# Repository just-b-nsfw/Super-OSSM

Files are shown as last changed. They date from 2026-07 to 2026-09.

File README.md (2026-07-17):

# Super-OSSM
Introducing the Super OSSM
A clean sheet, modular design, for a choose your OSSM build adventure.

Building on community improvements to the R+D design, the Super OSSM is compatible with 4 motor types, 2 PCBs, 3 rail & belt sizes, with 2 drive types to choose from, plus add-on modules.

My approach is to make it compact and compatible, only increasing the diameter by 15mm from the standard PitClamp ring, whilst being able to offer a wide range of compatibility for different-sized components. 

Large focus on - reducing the number of parts required, with the main unit being only 4 3D printed parts - simplifying the BOM, with standardised bolt sizes & lengths and using standard OSSM parts - ease of 3D printing, by minimising the need for support material - and improved assembly & serviceability,  with a twist-lock to access the motor and PCB. 
The final goal has been to improve the overall aesthetics so that the Super OSSM looks like a finished product rather than a DIY project.

Unfortunately, two design compromises were made - first, support and compatibility for the legacy iHSV motor was not possible, due to the backpack electronics that it has, making packaging inside the Super OSSM impossible - second, the use of 688 (8x16x8mm) bearings, rather than standard OSSM bearings, to aid ease of assembly.

Design features include a larger version of @Armpit’s PitClamp design with 120 position / 3° increments, and a fixed or folding clamp option for easy under-bed storage.

Support for @BuildingRandomStuff’s ALT PCB and the R+D PCB, with a translucent logo for the status LED.

An alternative drive option to use @SaladDressing’s Capstan drive system.

Support for -  
Motors	:	42AIM, 57AIM, 60AIM series & 60AIM40F  
PCB	:	R+D & ALT  
Rails	:	MGN12, MGN15 & HGR20  
Drive Mechanism	:	Belt or Capstan  
Belts	:	2MGT, 3MGT & HTD-3M  
Add-ons	:	Stroker Module 	(hopefully more in future)

Special thanks to @Frayd for their input and putting up with me being "extra" on calls to discuss the project.

I hope to have designed an OSSM for one and an OSSM for all.

b

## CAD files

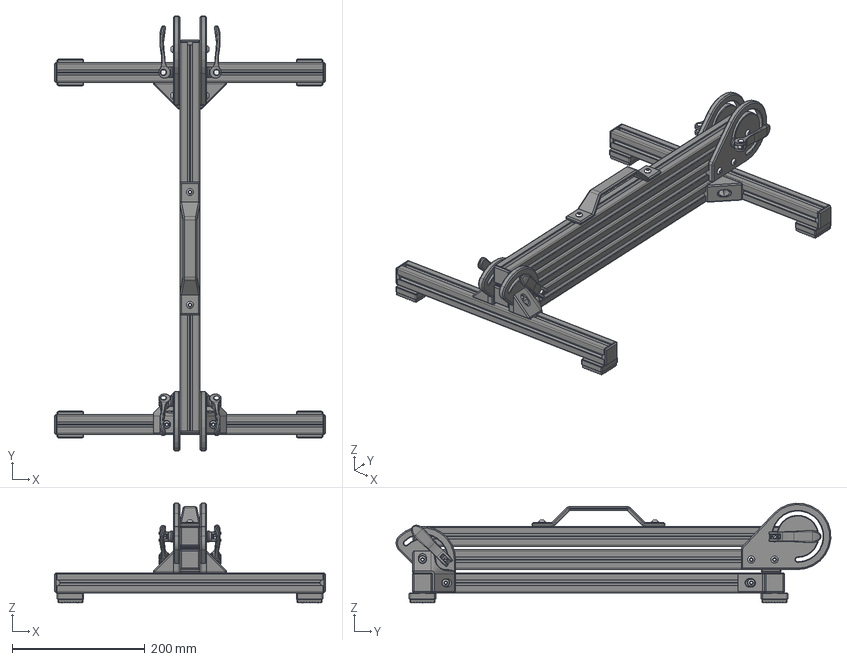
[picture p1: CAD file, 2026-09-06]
7. Z Stand/3030/Z Stand (3030) - Assembly.step
408.0 x 654.5 x 149.9 mm
5720K31_Clamping Handle with Threaded Stud x 4
91239A326_Button Head Hex Drive Screw x 4
91239A813_Button Head Hex Drive Screw x 10
91239A318_Button Head Hex Drive Screw x 10
91239A316_Button Head Hex Drive Screw x 2

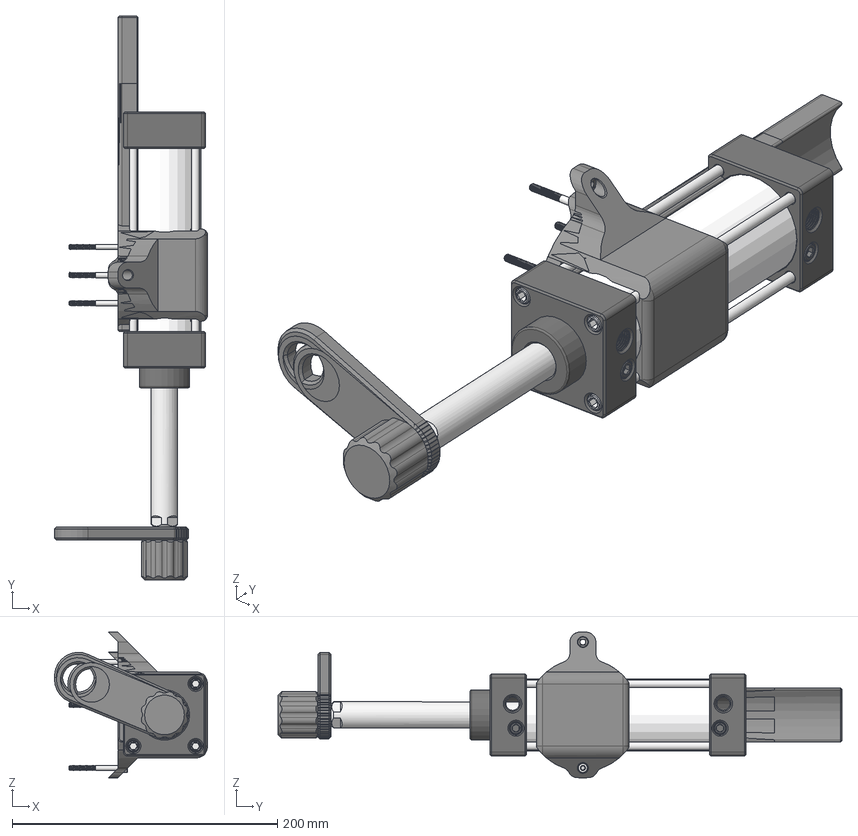
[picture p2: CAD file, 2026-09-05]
8. Add-on Modules/SC50 Stroker Module/SC50 Stroker Module - Assembly.step
115.5 x 425.5 x 110.0 mm
SC50X25_c
SC-50x25(0)_r
91292A132_18-8 Stainless Steel Socket Head Screw x 4

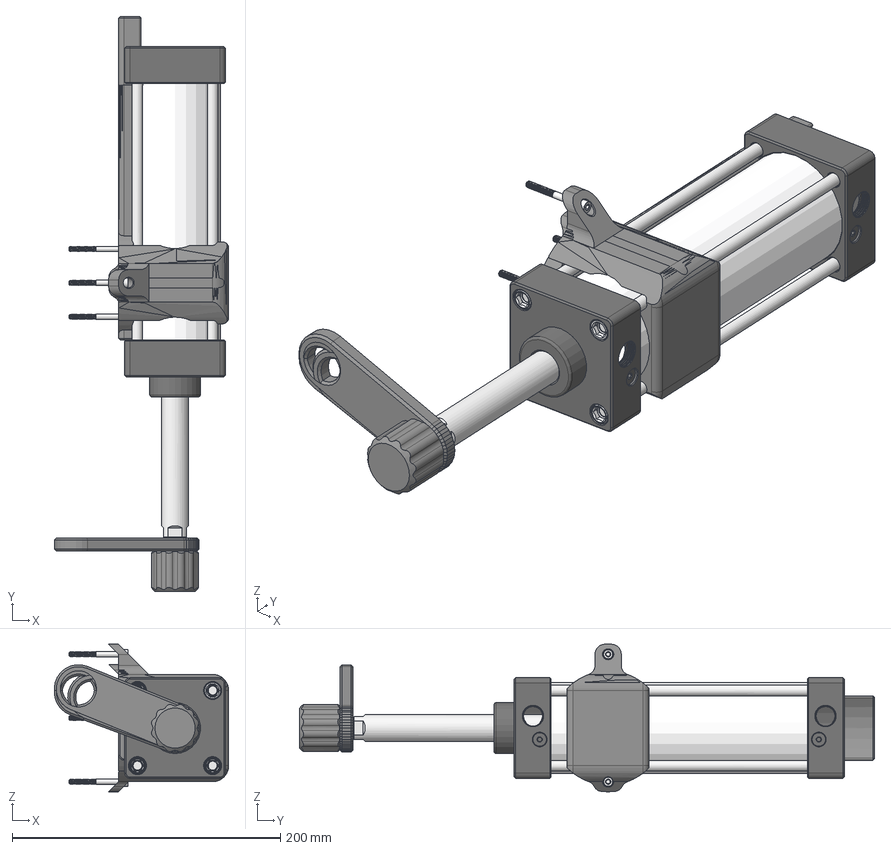
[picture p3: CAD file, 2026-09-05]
8. Add-on Modules/SC63 Stroker Module/SC63 Stroker Module - Assembly.step
130.0 x 428.5 x 110.0 mm
SC2563
SC63X25-S_00_rod
91292A132_18-8 Stainless Steel Socket Head Screw x 4

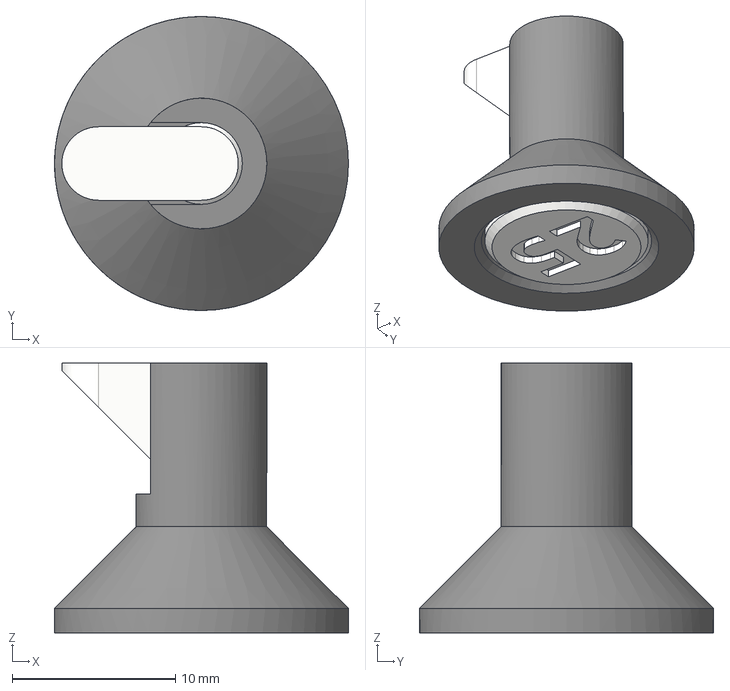
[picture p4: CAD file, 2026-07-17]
0. Test & Calibration/Step/Button (0.25).step
18.0 x 18.0 x 16.5 mm

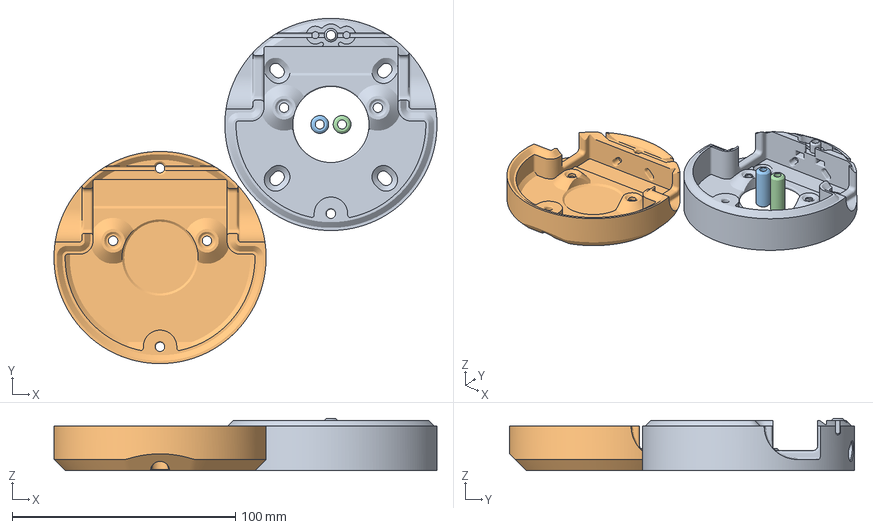
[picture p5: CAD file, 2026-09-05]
1. Super OSSM/Head (Std)/Head (Std).3mf
171.5 x 154.6 x 23.4 mm
Base (Std).stl
Cover (Std).stl
Bearing Carrier.stl x 2

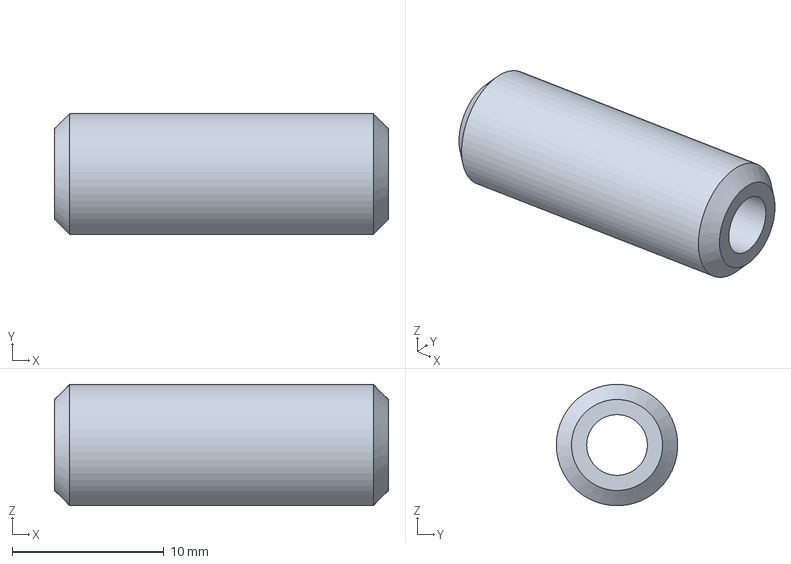
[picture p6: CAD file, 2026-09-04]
1. Super OSSM/Head (Std)/Step/Bearing Carrier.step
22.0 x 7.99 x 8.00 mm

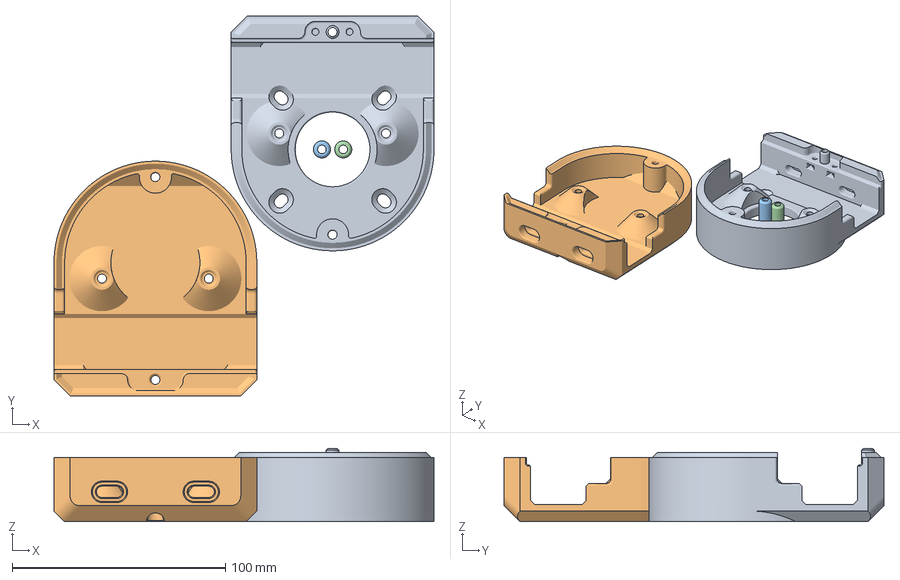
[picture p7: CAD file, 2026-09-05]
1. Super OSSM/Head (XL)/Head (XL).3mf
178.0 x 178.0 x 34.4 mm
Base (XL).stl
Cover (XL).stl
Bearing Carrier.stl x 2

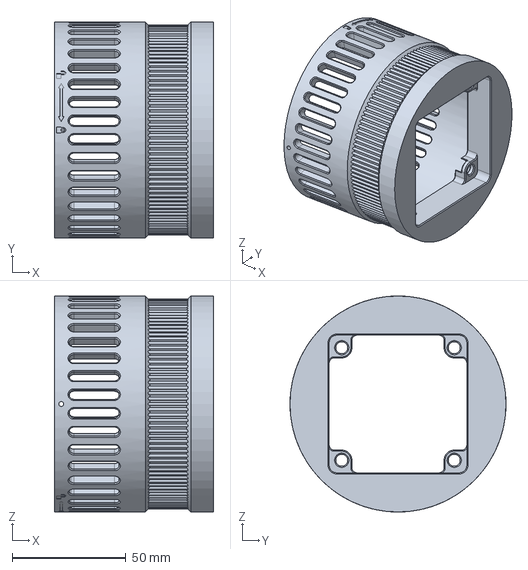
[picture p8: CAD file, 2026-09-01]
1. Super OSSM/Main Body/Step/Motor Ring (60AIM40F).step
70.0 x 95.0 x 95.0 mm

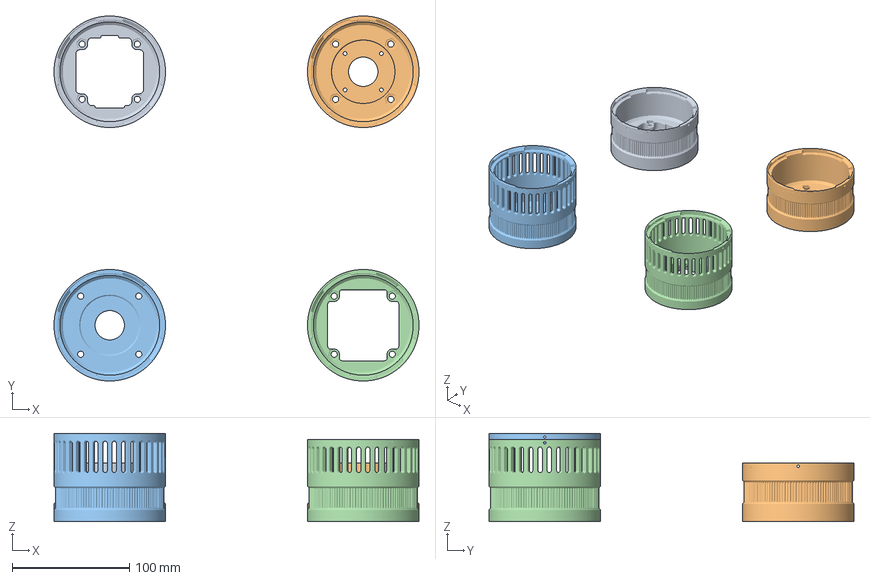
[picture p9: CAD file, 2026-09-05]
1. Super OSSM/Main Body/Super OSSM - Motor Ring.3mf
311.0 x 311.0 x 75.0 mm
Motor Ring (57AIM).stl
Motor Ring (42AIM).stl
Motor Ring (60AIM).stl
Motor Ring (60AIM40F).stl

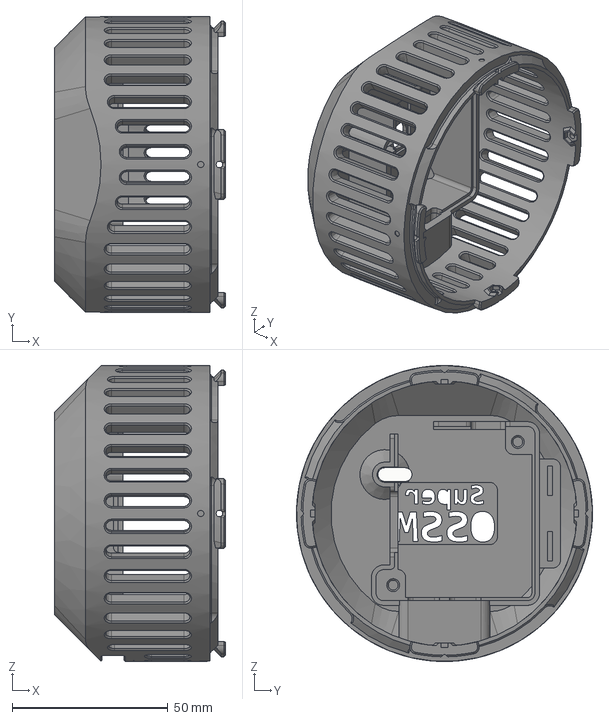
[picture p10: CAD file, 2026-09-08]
1. Super OSSM/PCB Housing/Step/ALT Cover (Dev).step
55.0 x 95.0 x 95.0 mm

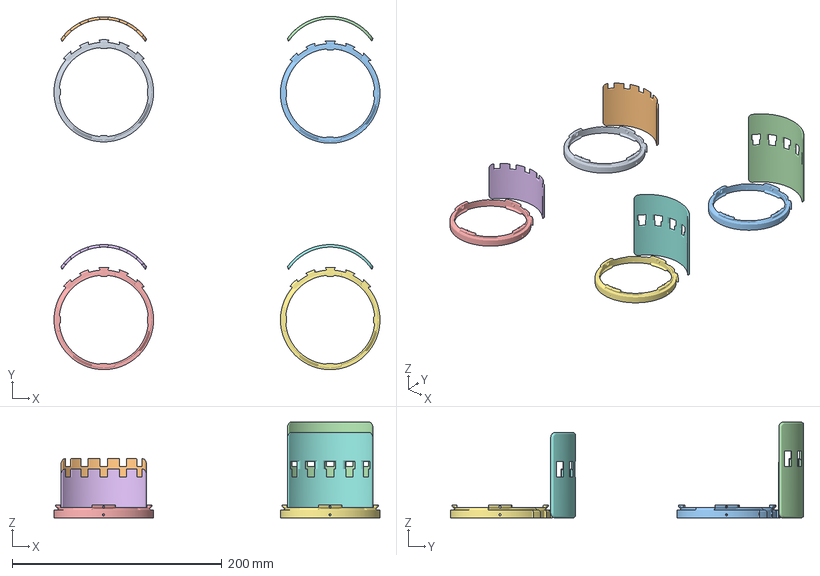
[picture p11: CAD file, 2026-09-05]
1. Super OSSM/Splash Guard/Splash Guard.3mf
311.0 x 337.0 x 91.5 mm
Ring.stl x 4
Guard (R+D).stl
Guard (R+D) (XL).stl
Guard (ALT).stl
Guard (ALT) (XL).stl

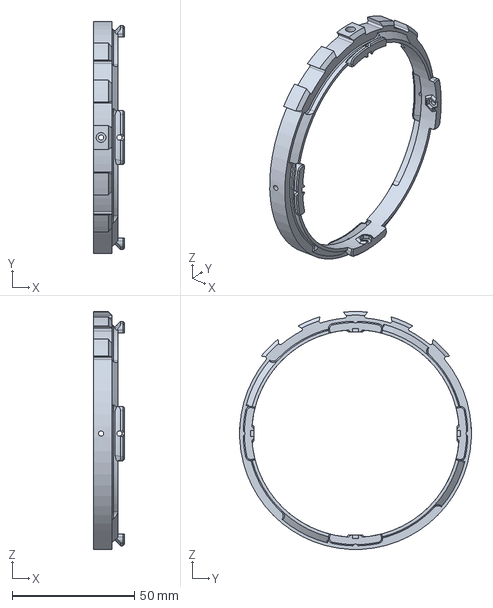
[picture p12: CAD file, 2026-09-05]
1. Super OSSM/Splash Guard/Step/Ring.step
12.5 x 95.0 x 97.5 mm

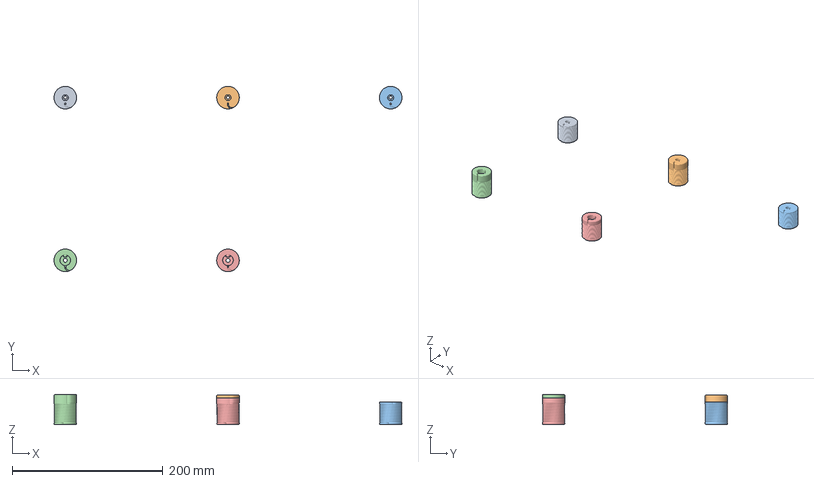
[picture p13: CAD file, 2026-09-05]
2. Motors & Pulleys/Capstan Drum/Capstan Drum.3mf
462.0 x 246.0 x 40.0 mm
Drum - 57AIM (Std).stl
Drum - 57AIM (XL).stl
Drum - 42AIM (std).stl
Drum - 60AIM (XL).stl
Drum - 60AIM40F (XL).stl

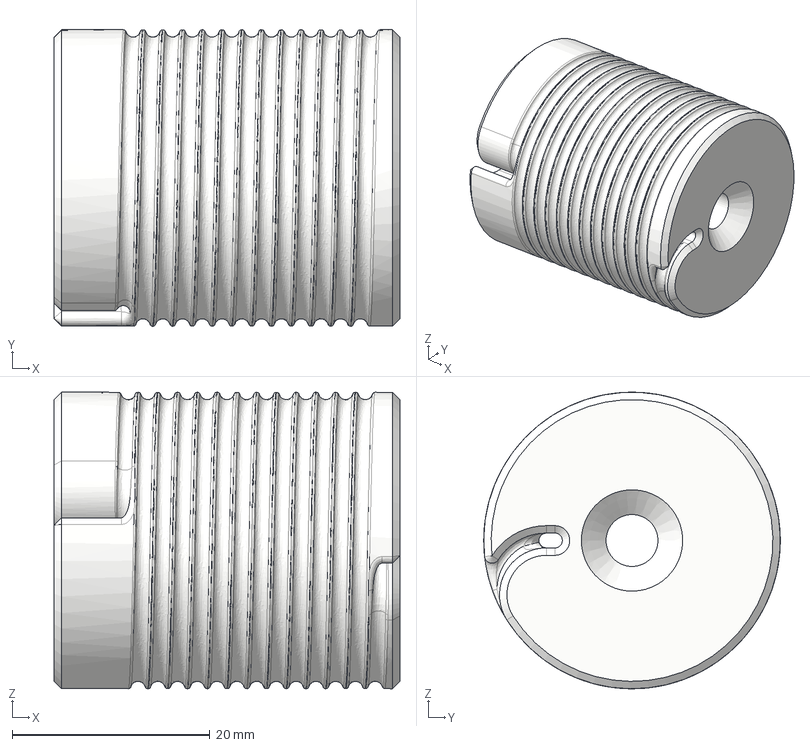
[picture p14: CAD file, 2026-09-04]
2. Motors & Pulleys/Capstan Drum/Step/Drum - 60AIM40F (XL).step
35.0 x 30.0 x 30.0 mm

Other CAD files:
1. Super OSSM/Head (XL)/Step/Bearing Carrier.step
2. Motors & Pulleys/Shaft Extender.3mf
3. Rail Ends/12mm Rail/12mm Rail.3mf
3. Rail Ends/12mm Rail/Step/Tensioner Adapter (12mm).step
0. Test & Calibration/Step/Button (0.20).step
0. Test & Calibration/Step/Button (0.30).step
0. Test & Calibration/Step/Button (0.35).step
0. Test & Calibration/Step/Super OSSM Calibration.step
0. Test & Calibration/Step/Tensioner Cover.step
0. Test & Calibration/Step/Thread.step
0. Test & Calibration/Step/Twist-lock A.step
0. Test & Calibration/Step/Twist-lock B.step
0. Test & Calibration/Stl/Button (0.20).stl
0. Test & Calibration/Stl/Button (0.25).stl
0. Test & Calibration/Stl/Button (0.30).stl
0. Test & Calibration/Stl/Button (0.35).stl
0. Test & Calibration/Stl/Super OSSM Calibration.stl
0. Test & Calibration/Stl/Thread.stl
0. Test & Calibration/Stl/Twist-lock A.stl
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

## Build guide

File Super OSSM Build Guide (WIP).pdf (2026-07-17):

## Build &

### Assembly Guide

Super

## OSSM

Introducing the Super OSSM A clean sheet, modular design, for a choose your OSSM build adventure.
Building on community improvements to the R+D design, the Super OSSM is compatible with 4 motor types, 2 PCBs, 3 rail & belt sizes, with 2 drive types to choose from, plus add-on modules.
My approach is to make it compact and compatible, only increasing the diameter by 15mm from the standard PitClamp ring, whilst
being able to offer a wide range of
compatibility for different sized components.

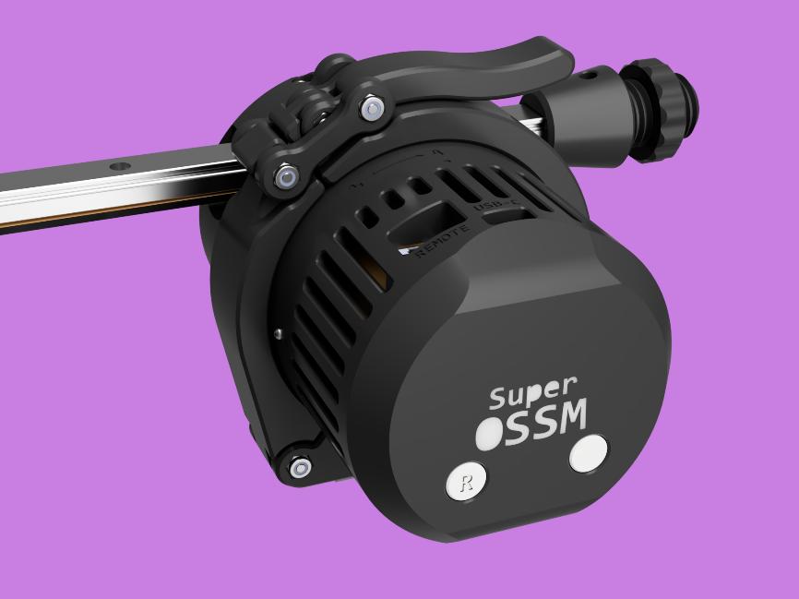
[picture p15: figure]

Large focus on - reducing the number of parts required, with the main unit being only 4 3D printed parts -simplifying the BOM, with standardised bolt sizes & lengths and using standard OSSM parts - ease of 3D printing, by minimising the need for support material - and improved assembly & serviceability, with a twist-lock to access the motor and PCB.
The final goal has been to improve the overall aesthetics so that the Super OSSM looks like a finished product rather than a DIY project.
Unfortunately, two design compromises were made - first, support and compatibility for the legacy iHSV motor was not possible, due to the backpack electronics that it has, making packaging inside the Super OSSM impossible - second, the use of 688 (8x16x8mm) bearings, rather than standard OSSM bearings, to aid ease of assembly.
Design features include a larger version of @Armpit’s PitClamp design with 120 position / 3° increments, and a fixed or folding clamp option for easy under-bed storage.
Support for @BuildingRandomStuff’s ALT PCB and the R+D PCB, with a translucent logo for the status LED. An alternative drive option to use @SaladDressing’s Capstan drive system.
Support for -
Motors | : 42AIM, 57AIM, 60AIM series & 60AIM40F
PCB | : R+D & ALT
Rails | : MGN12, MGN15 & HGR20
Drive Mechanism : Belt or Capstan
Belts | : 2MGT, 3MGT & HTD-3M
Add-ons | : Stroker Module | (hopefully more in future)
Special thanks to @Frayd for their input and putting up with me being "extra" on calls to discuss the project. I hope to have designed an OSSM for one and an OSSM for all.

b

This build and assembly guide is written to give an overview of the 3D printing, build and assembly process for the Super OSSM, from printing to play.
Print order and assembly steps are set out in a logical order for you to start building your Super OSSM as soon as the first parts are 3D printed. Due to the modularity of the design, not all configurations may be shown, and common sense may be needed. If bolt lengths are not specified in a step, please refer to the BOM. First time builders it is recommended that you join the Kinky Makers Discord server as it is a wealth of knowledge, a great place to chat with like-minded Kinky Makers, share and show-off projects, get help and technical or troubleshooting advice, and contribute to the Open-Source Sex Machine project.
Step 1 : Choose your OSSM build adventure
- Determine if you want a Standard, Lite or XL build - depending on the size of toys and attachments you plan to use, including any add-ons.
- Select an appropriate motor and rail size.
- Decide on drive system - belt or capstan.
- Choose your PCB.

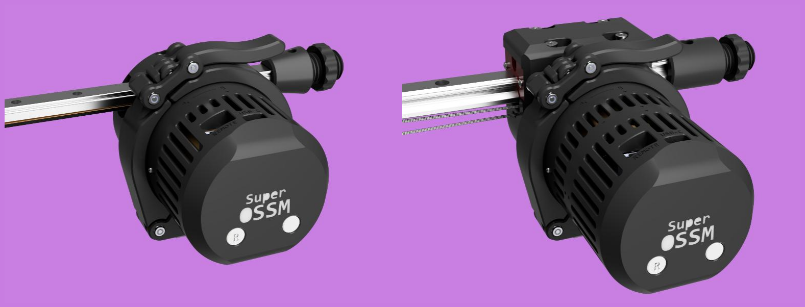
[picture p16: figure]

Recommended Configurations
Build | Head | PCB | Motor | Mechanism Drive | Belt | Rail Type | Rail Length | Attachment Weight | Add-ons*
Lite | Std | R+D ALT | 42AIM 57AIM | Belt | 2MGT x 12 mm | MGN12 | ≤ 400 mm | ≤ 2 kg | Stroker Module
Std | Std | R+D ALT | 57AIM | Belt Capstan | 2MGT x 15 mm 3MGT x 15 mm 1.5~2 mm Dyneema | MGN15 | 500 mm 350 ~ | 2 ~ 3kg | Stroker Module
XL | XL | R+D ALT | 60AIM 60AIM40F | Belt Capstan | 1.5~2 mm Dyneema HTD-3M x 15 mm | HG20R | ≥ 500 mm | ≥ 3 kg | Stroker Module

* High-torque motors are required to operate the Super OSSM as a stroker and poker simultaneously.
Parts are modular so you can customise your Super OSSM, depending on preferences and parts availability.

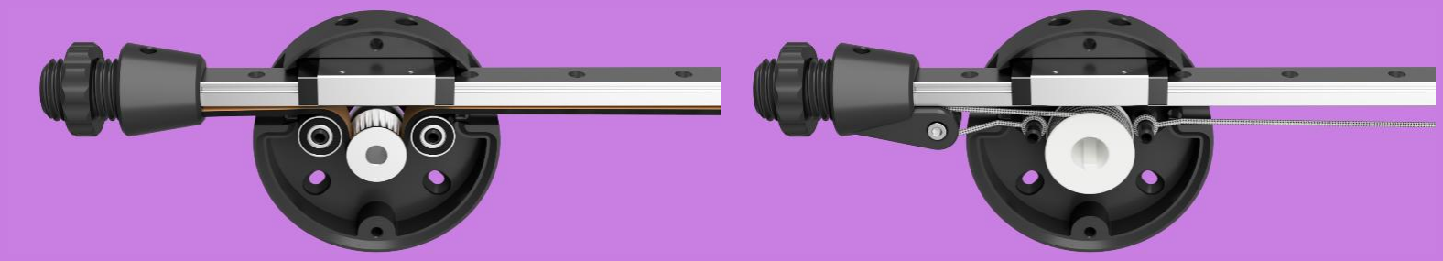
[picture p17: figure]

Compatible Motors
Motor | Protocol** | Dimensions | Shaft Size | Rated Speed | Max Speed | Torque | Voltage | Current | Power
42AIM10 | RS485 | ⌀ 53 x 42 mm | ⌀ 8 x 23 mm | 1000 RPM | 1500 RPM | 0.33 NM | 24 ~ 36 V | 1.5 A | 33 W
42AIM15 | RS485 | ⌀ 53 x 55 mm | ⌀ 8 x 27 mm | 1000 RPM | 1500 RPM | 0.48 NM | 24 ~ 36 V | 2.2 A | 50 W
42AIM30* | RS485 | ⌀ 53 x 70 mm | ⌀ 8 x 27 mm | 1000 RPM | 1500 RPM | 0.96 NM | 24 ~ 36 V | 4.4 A | 100 W
57AIM15 | RS485 | 57 x 57 x 57 mm | ⌀ 8 x 26 mm | 1000 RPM | 1500 RPM | 0.48 NM | 24 ~ 36 V | 2.2 A | 50 W
57AIM30* | RS485 | 57 x 57 x 72 mm | ⌀ 8 x 26 mm | 1000 RPM | 1500 RPM | 0.96 NM | 24 ~ 36 V | 4.4 A | 100 W
60AIM25* | RS485 | ⌀ 80 x 76 mm | ⌀ 14 x 30 mm | 1000 RPM | 1500 RPM | 2 NM | 36 V | 7.0 A | 200 W
60AIM40* | RS485 | ⌀ 80 x 90 mm | ⌀ 14 x 30 mm | 1000 RPM | 1500 RPM | 3 NM | 36 V | 10.0 A | 350 W
60AIM40F* | RS485 | 60 x 60 x 92 mm | ⌀ 14 x 30 mm | 1000 RPM | 1500 RPM | 2 NM | 36 V | 7.0 A | 200 W
* Recommended motors ** Recognisable by the GREEN terminal on the motor Note : 57AIM30 motor is often referred to as the “Gold” motor, and is the standard OSSM motor available from R+D. Comparison video of some of the available motors

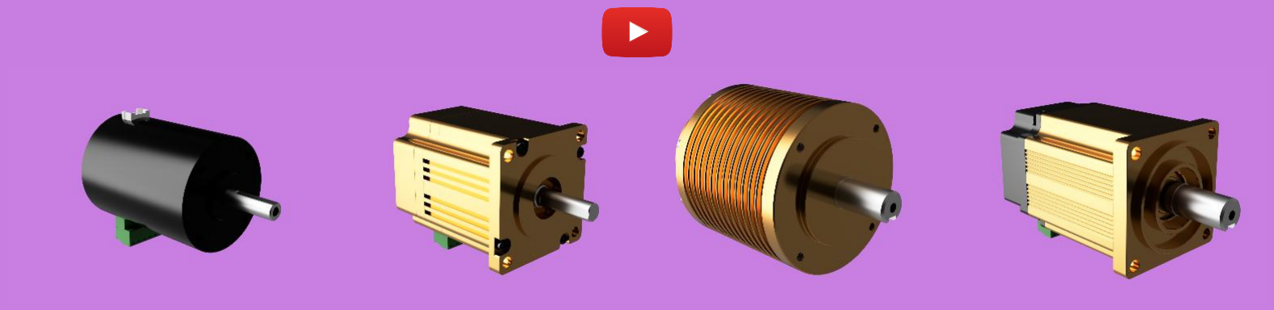
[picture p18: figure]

Compatible Rails
Rail | Dimensions | Hole Size | Spacing Hole | Length | Carriage | Dimensions | Bolt Size | Bolt Spacing
MGN12 | 12 x 8 mm | M3 | 25 mm | ≤ 400 mm | MGN12H | 45 x 27 x 13 mm | M3 x 3.5 mm | 20 x 20 mm
MGN15 | 15 x 10 mm | M3 | 40 mm | 350 ~ 500 mm | MGN15H | 59 x 32 x 16 mm | M3 x 4 mm | 25 x 25 mm
HGR20 | 20 x 17.5 mm | M5 | 60 mm | ≥ 500 mm | HGH20HA QHH20A | 92 x 44 x 30 mm | M5 x 6 mm | 50 x 32 mm

Max Stroke Length = Rail Length – Head Width – Rail Ends
Head Width : Std 70 mm | XL 95 mm
Rail Ends : MGN12 65 mm | MGN15 80 mm | HGR20 80 mm
Rail Length [400 mm] – Std Head Width [70 mm] – MGN15 Rail Ends [80 mm] = Max Stroke Length [250 mm]
Step 20 : Order parts
- See the BOM for the full parts list.
- You can order a kit from R+D - including 57AIM “Gold” motor, PCB + Remote, Rail & Hardware
- or source parts yourself | (required for alternative builds)

Step 3 : Calibrate your 3D printer Recommended print settings :
- Material | – PETG, ABS, PLA+ | DO NOT USE CF FILAMENTS!
- Nozzle | - 0.4 mm
- Perimeters - 4 | 8 for threaded rail ends | (minimum for strength vs print time)
- Infill | - 25% | 50% for threaded rail ends
- Layer height - 0.16 mm
- Wall order - Inside / Outside | (improves quality of threads and overhangs)
- Support | - NO for test prints | 40° for parts | (recommend paint-on supports)
Note : It is recommended that all parts for the project are printed on the same 3D printer to ensure that all parts fit together and account for any minor variations. Print the included calibration files to confirm dimensional accuracy :
- Check that the test print is the correct size 50 x 35 x 5 mm (± 0.1 mm) and the fasteners fit through the holes.
| | – Top holes are actual size - M3 = 3.0 mm
– Middle holes are 5% larger - M3 = 3.15 mm – Counterbores are 0.5 mm larger than the fastener head – M3 head 5.5 mm = 6.0 mm – Hexes are actual size for press fit so the captive nuts are securely – M3 hex 5.5 mm = 5.5 mm
- Print-in-place button has a 0.3 mm offsetfor a snug fit, which does notrattle, whilst being easy to print and operate smoothly. The button should require a firm push to free it after printing.
- Twist-lock should be a tight fit, to account for wear from use, and will operate more freely with a satisfying click after opening and closing a couple of times.

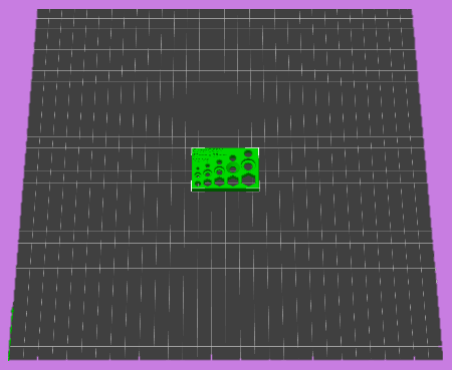
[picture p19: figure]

Troubleshooting :

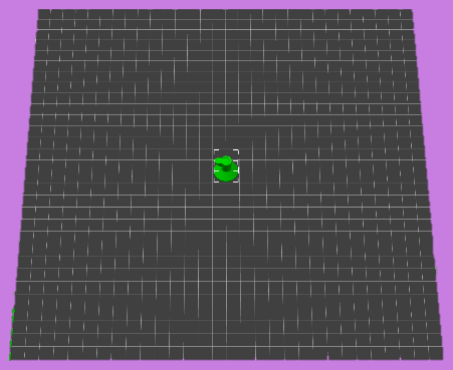
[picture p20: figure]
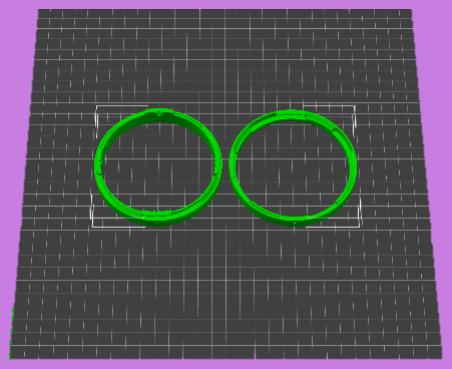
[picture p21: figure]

If you have difficulty with the test prints, check the following settings BEFORE you print the Super OSSM.
- Extrusion multiplier – complete a Flow Ratio test to ensure that your printer is not over-extruding as over-extrusion can cause the print-in-place button to print solid, undersized
holes and parts that do not fit together. | (OrcaSlicer has built-in calibration tools)
- XY contour compensation – if parts are over or undersized and do not fit together.
- XY hole compensation – if holes are undersized whilst the rest of the part is the correct
dimension [0.15 mm recommended] | (if your preferred slicer has the setting)
- Dynamic speeds and cooling for bridging and overhangs - there are parts that need clean 45° surfaces and bridged overhangs for embossed text.
- General print settings, including supports for best print quality and easy removal – whilst the Super OSSM has been designed to minimise support material where possible, there are areas where it is unavoidable such as spaces for captive nuts, PCB ports etc.

Step 4 : Get ready
Clear a workspace and organise your tools, you will need the following:
- Allen key set - 1.5 mm ~ 5 mm
- Small flat screwdriver
- Long-nose pliers
- Hook & pick set | (recommended to help remove support material)
Step 5 : Head (Base)
- Print the Base of the head - Std or XL depending on your build.
- Insert (4) M4 captive Nylon locknuts into the hex holes on the back side of the head.
- Insert (2) M4 bolts through the bearing carriers. (recommended to prevent accidental breakage)
- Insert (2) M3 captive nuts into the slot at the top of the head. | (Capstan drive only)
Step 6 : Motor
- Setup your motor by flashing it with the Web Flasher tool | (See Motor setup guide)
Step 7 : Motor Ring
- Print the appropriate Motor Ring for your motor.
- Insert (4) M5 captive locknuts into the slots inside the motor ring
- Slide the motor into the motor ring, from the head side.
- The motor will be secured with the bolts used to attach the head in the next step.
- If you have chosen either the 42AIM or 60AIM (round) motors, see additional steps 6A & 6B.
Step 7A : 42AIM
- Insert the motor into the motor ring from the PCB side and secure with (4) M3 x 6 mm countersunk bolts.
Step 7B : 60AIM
- DO NOT insert the (4) M5 Captive nuts into motor ring.
- Insert the motor into the motor ring from the PCB side and line up the mounting holes.
Step 8 : Attach the Head
- Place the Head (Base) over the motor shaft, aligning the mounting holes.
- Attach the Head to the motor and ring assembly with (4) M5 countersunk bolts.
Step 9 : Pulley
- Put the pulley on the motor shaft.
- Loosely fasten the grubscrews, as the pulley will be aligned with the belt later.
- If you are using a Capstan drive, you can secure the pulley to the shaft with the countersunk bolt.
Step 10 : Bearings | (Not required for Capstan drive)
- Place (4) 688 bearings over each bearing carrier.
Step 11 : Rail
- Add the rail linear bearing block to the Head.
- You will need to use the spacer for the MGN12 rail.
- Secure the linear bearing with (2) M3 or M5 bolts.

Step 12 : Belt Drive
Step 12A: Tensioner
- Print the appropriate size Tensioner and Keystone for your rail size and belt type.
- Print Tensioner cap.
- Insert (1) M4 nut into the slot in the tensioner through the large opening for the rail.
- Insert (1) M4 bolt from the opposite side to hold the nut in place.
- Only screw the bolt in until the nut is flush with the end of the bolt, as this nut and bolt is used to tighten the belt.
- Feed the belt through the slot below the rail opening.
- Place the keystone on the belt, leaving a small tail (2 ~ 3 cm).
- Pull the belt back through the slot until the Keystone is wedged firmly in place.
- Push the Tensioner end on to the rail, until it is all the way in the slot.
- Screw the Tensioner cap on the end, tucking the tail of the belt inside.
Step 12B: Belt
- Feed the belt over the bearings and under the pulley.
- Gently pull tight to remove any slack.
- Cut the belt to length, it should end just before the last hole on the rail.
Step 12C: Fixed End
- Print the appropriate size Fixed End and Belt Clamp for your rail size and belt type.
- Put the Belt Clamp between the belt and rail , aligning the hole with the last hole of the rail.
- Slide the Fixed End over the Rail, Belt and Belt Clamp.
- Secure in place with (1) M4 or M5 locknut and (1) M4 or M5 bolt.
- The head of the bolt will sitin the counterbore ofthe rail and pullthe Fixed End tight against the underside of the rail, sandwiching the Belt and Belt Clamp in place.
Step 12D: Align the Pulley
- Gently move the rail through the full stroke length checking the belt tracking and pulley alignment.
- Adjust the pulley so that the belt does not touch either side through the full range.
- Secure the pulley to the motor shaft by tightening the grubscrews.

Step 14 : Cover
- Print the Cover for the head - Std or XL depending on your build.
- Remove the (2) M4 bolts in the bearing carriers.
- Place the cover over the head assembly.
- Secure in place with (4) M4 bolts on the face of the Cover, and (2) M3 or M5 bolts at the top into the Linear Bearing carriage.
- Make sure the cover is fully closed without a gap before you insert the bolts at the top, to prevent cross threading the threaded holes of Linear Bearing carriage.
Step 15 : Tension
- Tension the Belt or Dyneema rope using the bolt in Tensioner or both Capstan Rail ends.
- DO NOT TENSION UNLESS THE COVER IS BOLTED IN PLACE! - Tensioning without the Cover being bolted in place can cause damage to the bearing carriers and or mounting for the Linear Bearing.
Step 16 : PCB
- Flash OSSM firmware on to the PCB. | (See Firmware setup guide)
- Attach the Motor wires to the PCB.
Step 13 : Capstan Drive
Step 13A: Rail Ends
- Print appropriate size (2) Capstan Rail Ends and (1) Cap
- Insert (1) M4 nut into the slot in the rail end through the large opening for the rail.
- Insert (1) M4 bolt from the opposite side to hold the nut in place.
- Only screw the bolt in until the nut is flush with the end of the bolt, as this nut and bolt is used to tighten the belt.
- Insert (2) U604-ZZ Deep Groove bearings into the slot.
- Secure in place using (2) M4 x 25 mm bolts and (2) M4 Nylon locknuts.
- Push the Rail Ends on to either side of the rail, until it is all the way in the slot.
Step 13B: Capstan Rope
- Place the Dyneema rope in the RIGHT slot at the top of the head.
- Wrap the end of the Dyneema around the post at the top of the head.
- Secure the end of the Dyneema in place with (1) M3 bolt and (1) M3 flat washer.
- Feed the opposite end of the Dyneema through the (2) idler pulleys in the RIGHT rail end from the top.
- Run the Dyneema along the underside of the rail to the pulley.
- Wrap the Dyneema 8 times around the pulley starting from the back.
- Run the Dyneema along the underside of the rail to the opposite rail end.
- Feed the running end of the Dyneema through the (2) idler pulleys in the LEFT rail end from the bottom.
- Place the Dyneema rope in the LEFT slot at the top of the head.
- Wrap the end ofthe Dyneema around the post atthe top of the head, pulling tightto remove ALL slack from the rope.
- Secure the end of the Dyneema in place with (1) M3 bolt and (1) M3 flat washer.

Step 17 : PCB Housing
- Print the PCB housing for your PCB type – R+D or ALT PCB
- Print the Diffuser using translucent filament and insert in place.
(Recommend 100% infill with Concentric Top, Bottom & Infill pattern, XY Contour -0.2 mm)
- Insert the M3 captive nuts.
- Insert the PCB into the PCB Housing, making sure the buttons and ports align correctly.
- Secure in place with M3 x 10 mm bolts.
- Insert (4) M2 captive nuts around the inside perimeter.
- Plug in Motor.
- Twist the PCB Housing assembly in place on the rear of the Motor Ring until it clicks and the dot lines up with the lock icon.
- Lock in place with (2) M2 screws. | (Optional)
Step 18 : Clamp
- Print the parts of the Clamp
- Insert the M4 captive Nylon locknuts into their slots in the Base and Dogbone.
- Insert the M4 captive nut into the slot in the Handle.
- Using M4 x 25 mm bolts attach the Arm(s) to the base.
- Using (1) M4 x 12 mm bolt attach the Handle to the Locking arm.
- Using (1) M4 x 25 mm bolt and (2) M4 flat washers attach the Dogbones to the handle.
- Insert the spacer between the Dogbones and secure with (1) M4 x 25 mm bolt.
- Insert (2) M6 x 12 mm bolts into the holes in the base and attach (1) M6 Double T-nut or (2) M6 Single T-nuts.
- Attach the Clamp to a stand or mounting of your choice.
Step 19 : End Effectors
- Print and attach the End Effector of your choice to the M24 thread on Rail End(s)
Step 20 : Enjoy
- Connect and Control your Super OSSM with a Remote, Web Controller or App.
- Share your build in the Kinky Makers Discord.
- Enjoy using your Super OSSM!

Add-on : Stroker Module

Step A : Print
- Print the appropriate size Add-on parts for your Super OSSM head type, Cylinder size and length.

Step B : Stroker Base
- Release all the tension from the Belt or Capstan Rope, by backing off the tensioning bolt(s).
- Remove the (2) M4 bolts in the middle that go through the bearing carriers.
- Place the Stroker Base on the face of the Head.
- Secure in place with (2) M4 bolts 10 mm longer than the ones you removed.
- Re-tension the Belt or Capstan Rope.

Step C : Stroker Top
- Remove the (2) M4 bolts at the top and bottom of the head.
- Place the Cylinder on the Stroker Base.
- It is important that you print the correct length Stroker Base as it keeps the Stroker in position during use.
- Place the Stroker Top over the cylinder.
- Secure in place with (2) M4 bolts 10 mm longer than the ones you removed.

Step D : Stroker Cylinder
- Connect the Stroker Arm to the Cylinder with the Stroker Cap.
- Connect the Stroker Arm to the rail, you can use a Jam nut or End Effector.

Step E : Stroker Receiver
- Connect the Stroker Arm to the Cylinder with the Stroker Cap.
- Connect the Stroker Arm to the rail, you can use a Jam nut or End Effector.

Step F : Homing & Control
- Select Stroker Mode on your Remote, Web Controller or App.
- Home your Super OSSM with the Stroker Module attached.

Bill of Materials (BOM)

Qty | Part | Description | Notes
| | Electronics
1 | Motor | 42AIM, 57AIM, 60AIM, 60AIM40F | See recommended builds for more information
1 | PCB | R+D or ALT
1 | * Remote | Wired remote or RADR | Wired remote for R+D PCB only
| | Rails
1 | MGN12 | ≤ 400 mm | Std Head
1 | MGN15 | 350 ~ 500 mm | Std Head
1 | HGR20 | ≥ 500 mm | XL Head
Select one, size / type depending on your Super OSSM build
1 | MGN12H | MGN12 rail | Std Head
1 | MGN15H | MGN15 rail | Std Head
1 | HGH20HA / QHH20A | HGR20 rail | XL Head
Select one, size / type depending on your Super OSSM build
4 | M3 x 12 mm | Socket head | MGN12 rail
4 | M3 x 10 mm | Socket head | MGN15 rail
4 | M5 x 15 mm | Socket head | HGR20 rail
Select one, size / type depending on your Super OSSM build
| | Belts & Pulleys
1 | 2MGT x 12 mm | ~1 m length, cut to size | MGN12 rail
1 | 3MGT x 12 mm | ~1 m length, cut to size | MGN12 rail
1 | 2MGT x 15 mm | ~1 m length, cut to size | MGN15 rail
1 | 3MGT x 15 mm | ~1 m length, cut to size | MGN15 rail
1 | HTD-3M x 15 mm | ~1 m length, cut to size | HGR20 rail
1 | Dyneema 1.5 mm | ~2 m length, cut to size | Capstan Drive
Select one, size / type depending on your Super OSSM build
1 | 2MGT 20T 8 mm Bore Pulley | 12 ~ 15 mm for belt width | Motors - 42AIM, 57AIM
1 | 3MGT 20T 8 mm Bore Pulley | 12 ~ 15 mm for belt width | Motors - 42AIM, 57AIM
1 | HTD-3M 25T 14 mm Bore Pulley | 15 mm for belt width | Motors - 60AIM, 60AIM40F
1 | Capstan Pulley | Print version for motor type & head size | Motors - ALL
Select one, size / type depending on your Super OSSM build
| | * Bearings
8 | 688-ZZ / 688-2RS | 8 x 16 x 5 mm | Required for Belt drive only
| | Head
4 | M4 x 30 mm | Socket head | Std Head
4 | M4 x 50 mm | Socket head | XL Head
4 | M4 nut | Nylon locknut
| | Motor Ring
4 | +M3 x 6 mm | Countersunk head | Motor Ring - 42AIM
4 | M5 x 15 mm | Countersunk head | Std Head | Motor Ring - 60AIM
4 | M5 x 20 mm | Countersunk head | Std Head | Motor Ring - 42AIM, 57AIM, 60AIM40F XL Head | Motor Ring - 60AIM
4 | M5 x 25 mm | Countersunk head | XL Head | Motor Ring - 42 AIM, 57AIM, 60AIM40F
4 | +M5 nut | Nylon locknut | Motor Ring - 42 AIM, 57AIM, 60AIM40F
Select, size / type depending on your Super OSSM build

Qty | Part | Description | Notes
| | PCB Housing
4 | * M2 nut | Standard nut | Optional to lock the PCB cover
2 | * M2 x 6 mm | Button or Socket head | Optional to lock the PCB cover
# | M3 nut | Standard nut | (3) R+D PCB | (2) ALT PCB

# | M3 x 10 mm | Button or Socket head | (3) R+D PCB | (2) ALT PCB

| | * Rail Ends
1 | M4 nut | Standard nut | Tensioner
1 | M4 x 25 mm | Socket head | Tensioner (MGN12 & MGN15)
1 | M4 x 30 mm | Socket head | Tensioner (HGR20)
1 | M3 nut | Nylon locknut | Fixed end (MGN12 & MGN15)
1 | M3 x 18 mm | Socket head | Fixed end (MGN12 & MGN15)
1 | M5 nut | Nylon locknut | Fixed end (HGR20)
1 | M5 x 22 mm | Socket head | Fixed end (HGR20)
Select, size / type depending on your Super OSSM build
| | * Capstan Drive
2 | M3 washer | Flat washer | Std Head - 7 mm OD | XL Head - 10 mm OD
2 | M3 nut | Standard nut
2 | M3 x 6 mm | Socket head | Std Head
2 | M3 x 10 mm | Socket head | XL Head
4 | U604ZZ | Groove bearing 4 x 13 x 4 mm
6 | M4 nut | Nylon locknut
4 | M4 x 25 mm | Socket head | Bearings
2 | M4 x 50 mm | Socket head | Tensioner
1 | M4 x ## mm | Countersunk head | Pulley to motor (42AIM & 57AIM)
1 | M5 x ## mm | Countersunk head | Pulley to motor (60AIM & 60AIM40F)
| | Clamp
2 | M4 washer | Flat washer | Max OD 8 mm
1 | M4 nut | Standard nut
4 | M4 nut | Nylon locknut
1 | M4 x 12 mm | Socket head
4 | M4 x 25 mm | Socket head
2 | M6 x 12 mm | Socket head
1 | M6 Double T-Nut | 25 mm hole spacing | Can use (2) M6 Single T-nuts
# | Furniture Pad | 38 mm / 1.5 inch self-adhesive | Desk and Bed mounts

| | * Optional part ⁺ Additional part
Note : Due to the modular design of the Super OSSM, parts for all build configurations listed in the BOM. Please check the Notes and compile YOUR parts list carefully before ordering.

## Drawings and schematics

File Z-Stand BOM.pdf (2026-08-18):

# Bill of Materials (BOM)

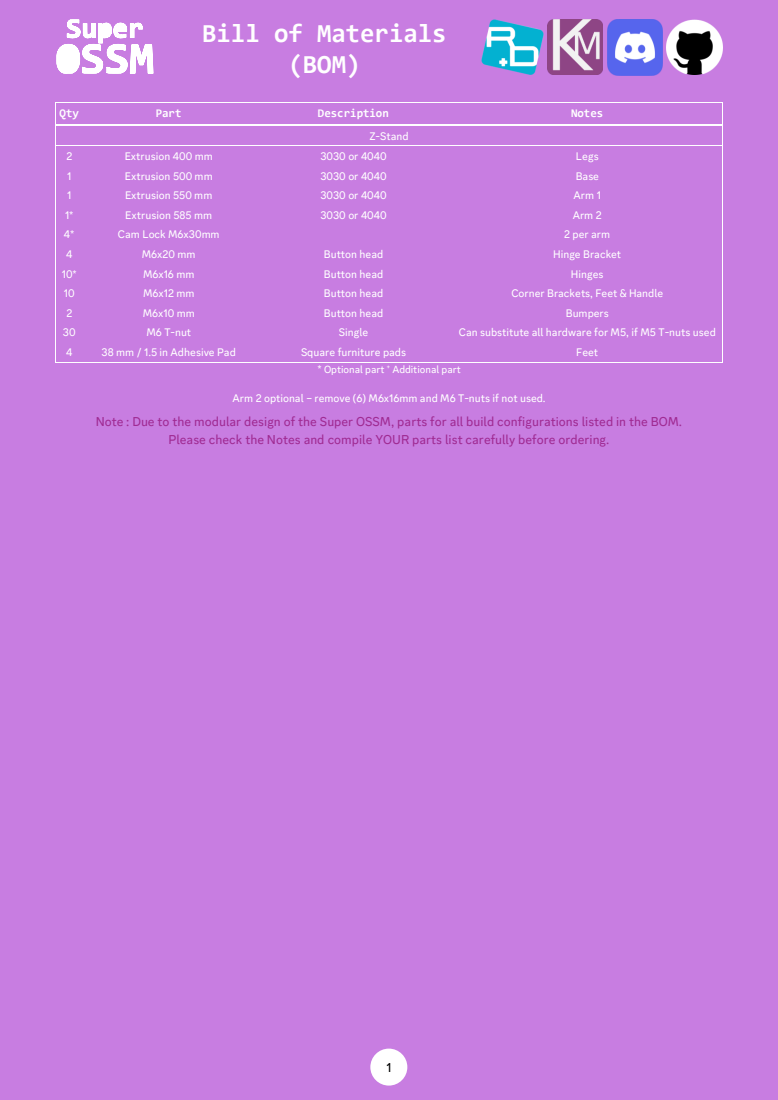
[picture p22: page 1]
Qty; Part; Description; Notes; Z-Stand; Extrusion 400 mm; Legs; Extrusion 500 mm; Base; Extrusion 550 mm; Arm 1; Extrusion 585 mm; Arm 2; Cam Lock M6x30mm; 2 per arm; Button head; Hinge Bracket; Hinges; Corner Brackets, Feet & Handle; Bumpers; M6 T-nut; Single; Can substitute all hardware for M5, if M5 T-nuts used; 38 mm / 1.5 in Adhesive Pad; Square furniture pads; Feet

* Optional part ⁺ Additional part

Arm 2 optional – remove (6) M6x16mm and M6 T-nuts if not used.

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

Please check the Notes and compile YOUR parts list carefully before ordering.

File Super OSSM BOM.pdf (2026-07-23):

# Bill of Materials (BOM)

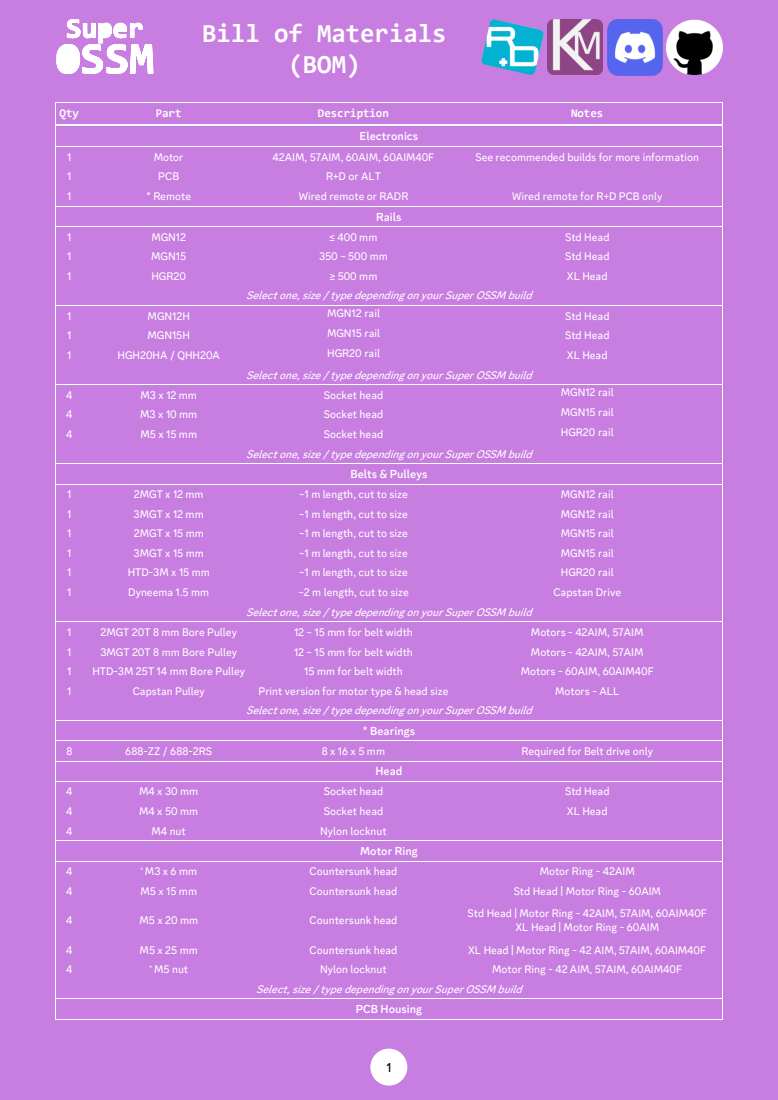
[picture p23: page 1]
Qty; Part; Description; Notes; Electronics; Motor; 42AIM, 57AIM, 60AIM, 60AIM40F; See recommended builds for more information; PCB; R+D or ALT; * Remote; Wired remote or RADR; Wired remote for R+D PCB only; Rails; MGN12; Std Head; MGN15; HGR20; XL Head; MGN12H; MGN12 rail; MGN15H; MGN15 rail; HGH20HA / QHH20A; HGR20 rail; Socket head; Belts & Pulleys; 2MGT x 12 mm; ~1 m length, cut to size; 3MGT x 12 mm; 2MGT x 15 mm; 3MGT x 15 mm; HTD-3M x 15 mm; Dyneema 1.5 mm; ~2 m length, cut to size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

Select one, size / type depending on your Super OSSM build

XL Head | Motor Ring - 60AIM

Select, size / type depending on your Super OSSM build

# Bill of Materials (BOM)

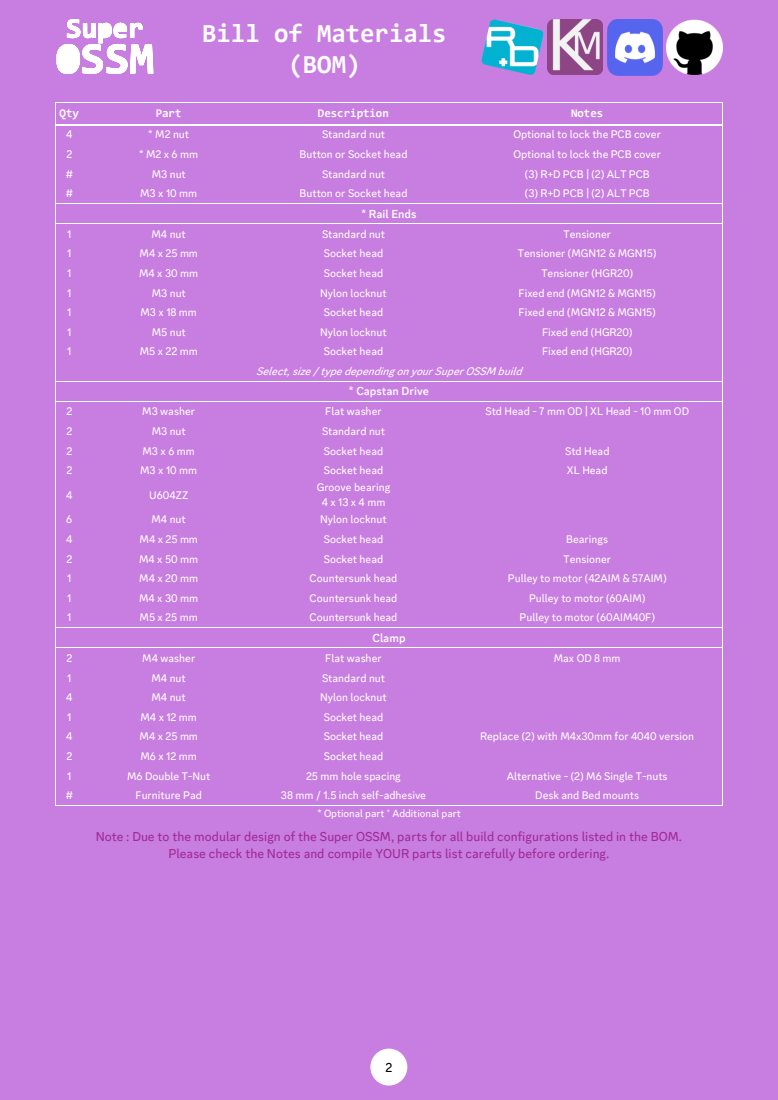
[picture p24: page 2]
Qty; Part; Description; Notes; * M2 nut; Standard nut; Optional to lock the PCB cover; Button or Socket head; M3 nut; (3) R+D PCB | (2) ALT PCB; * Rail Ends; M4 nut; Tensioner; Socket head; Tensioner (MGN12 & MGN15); Tensioner (HGR20); Nylon locknut; Fixed end (MGN12 & MGN15); M5 nut; Fixed end (HGR20); * Capstan Drive; M3 washer; Flat washer; Std Head - 7 mm OD | XL Head - 10 mm OD; Std Head; XL Head; Groove bearing; Bearings; Countersunk head; Pulley to motor (42AIM & 57AIM)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

Select, size / type depending on your Super OSSM build

* Optional part ⁺ Additional part

Note : Due to the modular design of the Super OSSM, parts for all build configurations listed in the BOM.

Please check the Notes and compile YOUR parts list carefully before ordering.

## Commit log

2026-07-17 Create 0. Test & Calibration
2026-07-17 Create Test & Calibration
2026-07-17 Upload stl
    [12mm Rail Spacer.stl, 12mm Rail.3mf, 15mm Rail.3mf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]
2026-07-17 Upload 3030
    [Clamp 3030.3mf, Dogbone (Bolt).stl, Dogbone (Nut).stl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]
2026-07-17 Rename files
    [Bed Mount 3030.3mf, Cuff Adapter 3030.3mf, Fixed Base 3030.stl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]
2026-07-17 Reorder folders
    [12mm Rail Spacer.stl, 12mm Rail.3mf, 15mm Rail.3mf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]
2026-07-17 Placeholders added
    [SC50 Stroker Arm (Std).stl, SC50 Stroker Arm (XL - Capstan).stl, SC50 Stroker Arm (XL).stl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]
2026-07-17 Motor PDFs added
2026-07-17 Updated recommended print settings
2026-07-17 4040 Added
    [Bed Mount 3030.stl, Bed Mount 4040.stl, Clamp 3030.3mf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]
2026-07-17 .3mf files updated
    [Bed Mount 4040.stl, Bed Mount.3mf, Bed Mount.stl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]
2026-07-17 Quick-shot added
    [Fleshlight (Quick-shot) Adapter.stl]
2026-07-17 step files added
    [12mm Rail Spacer.step, Capstan Adapter (15mm).step, Capstan Adapter (20mm).step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]
2026-07-17 reversible bracket
    [3030 Hinge Bracket B (L).stl, 3030 Hinge Bracket B (R).stl, 3030 Hinge Bracket B.stl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]
2026-07-17 missing file
    [Fixed Base 3030.step, Fixed Base 3030.stl, Folding Arm 3030.step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]
2026-07-17 full assembly
2026-07-18 update for new capstan drum
    [Base (Std).step, Base (Std).stl, Base (XL).step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]
2026-07-18 new Capstan drum design
    [Drum - 42AIM (std).step, Drum - 57AIM (Std).step, Drum - 60AIM (XL).step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]
2026-07-18 repaired concentricity
    [Drum - 42AIM (std).step, Drum - 57AIM (Std).step, Drum - 60AIM (XL).step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]
2026-07-18 further refinement
    [Drum - 42AIM (std).step, Drum - 57AIM (Std).step, Drum - 60AIM (XL).step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]
2026-07-21 additional end effectors added
    [Double Adapter.step, Double Adapter.stl, Quick Change Ring (40mm).step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]
2026-07-23 BOM added
2026-07-23 Blank Cover added
    [Blank Cover.step, Blank Diffuser.step, Blank Diffuser.stl]
2026-07-23 reversed direction of drum
    [Drum - 42AIM (std).step, Drum - 57AIM (Std).step, Drum - 60AIM (XL).step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]
2026-07-23 Splash guard added
    [Blank Cover.step, Guard (ALT) (XL).step, Guard (ALT) (XL).stl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]
2026-07-23 full assemblies added
2026-07-24 improved printability
    [Fleshlight (Pilot) Adapter.step, Fleshlight (Pilot) Adapter.stl, Guard (ALT) (XL).step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]
2026-07-26 fixed chamfer
    [Handle.step, Handle.stl]
2026-07-30 Drum - 57AIM (XL) added
    [Drum - 57AIM (XL).f3d, Drum - 57AIM (XL).stl, Motors & Drive Pulleys.step]
2026-08-02 fixed rail tolerance
    [Capstan Adapter (20mm).step, Capstan Adapter (20mm).stl, Fixed Adapter (20mm).step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]
2026-08-04 updated design for rope clearance
    [Capstan Adapter (20mm).step, Capstan Adapter (20mm).stl]
2026-08-04 fixed offset for rail
    [Capstan Adapter (15mm).step, Fixed Adapter (12mm).step, Fixed Adapter (12mm).stl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]
2026-08-04 changed chamfer to match
    [Double Double.step, Double Double.stl]
2026-08-04 thinner design with equal spacing
    [Guard (ALT) (XL).step, Guard (ALT).step, Guard (R+D) (XL).step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]
2026-08-04 R insert added
    [R Insert.step, R Insert.stl]
2026-08-15 Fusion 360 Assembly
2026-08-15 .f3d export
    [Super OSSM Clamp (3030).f3d, Super OSSM Clamp (4040).f3d, Z Stand (3030).f3d]
2026-08-15 fixed empty .step file
    [ALT Cover (Dev).step, ALT Cover.step]
2026-08-18 Z-stand BOM added
2026-09-01 added support for CA bearing
    [Base (XL).step, Cover (XL).step, Cover (XL).stl]
2026-09-01 fixed capacitor clearance
    [ALT Cover (Dev).step, ALT Cover (Dev).stl, ALT Cover.step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]
2026-09-01 added tolerance for motor flange
    [Motor Ring (57AIM).step, Motor Ring (57AIM).stl, Motor Ring (60AIM40F).step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]
2026-09-01 changed belt clamp geometry
    [Tensioner Adapter (12mm).step, Tensioner Adapter (12mm).stl, Tensioner Adapter (15mm).step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]
2026-09-01 added grubscrews for D shaft
    [Drum - 42AIM (std).step, Drum - 42AIM (std).stl, Drum - 57AIM (Std).step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]
2026-09-01 shaft extender
    [Shaft Extender - 60AIM.step, Shaft Extender - 60AIM.stl]
2026-09-02 fixed wrong button press
    [ALT Cover (Dev).step, ALT Cover (Dev).stl, ALT Cover.step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]
2026-09-02 Prusa holes
    [Base (XL).step, Base (XL).stl, Cover (XL).step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]
2026-09-04 separated bearing carriers
    [Base (Std).step, Base (Std).stl, Bearing Carrier.step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]
2026-09-04 improved PCB hold down
    [R+D Cover.step, R+D Cover.stl]
2026-09-04 added 0.1mm shaft tolerance
    [Drum - 42AIM (std).step, Drum - 42AIM (std).stl, Drum - 57AIM (Std).step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]
2026-09-04 new angle
    [Tensioner Adapter (12mm).step, Tensioner Adapter (12mm).stl, Tensioner Adapter (15mm).step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]
2026-09-04 removed sharp edges
    [Tensioner Adapter (12mm).step, Tensioner Adapter (12mm).stl, Tensioner Adapter (15mm).step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]
2026-09-05 Rebranded + updates
    [Clamp 3030.3mf, Dogbone (Bolt).step, Dogbone (Nut).step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]
2026-09-05 .3mf updated
    [SC50 Stroker Module.3mf, SC63 Stroker Module.3mf]
2026-09-06 .3mf updated + Prusa holes
    [3030 Bumper [2x].stl, 3030 Bumper.step, 3030 Foot [4x].stl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]
2026-09-06 repositioned brake chopper
    [ALT Cover (Dev).3mf, ALT Cover (Dev).step, ALT Cover (Dev).stl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]
2026-09-08 sliding & offset mounts added
    [Bed Mount.3mf, Bed Mount.step, Bed Mount.stl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]
2026-09-08 .3mf added
    [Side Offset Mount.3mf, Sliding Mount.3mf]
2026-09-08 fixed brake chopper slots
    [ALT Cover (Dev).3mf, ALT Cover (Dev).step, ALT Cover (Dev).stl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]
2026-09-08 updated bolt depth
    [PitClamp -XL- (3030).f3d, PitClamp -XL- (3030).step, Side Offset Mount 3030.step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]
2026-09-27 corrected rail tolerance
    [Capstan Adapter (15mm).step, Capstan Adapter (15mm).stl, Capstan Rail Ends (15mm).3mf]
